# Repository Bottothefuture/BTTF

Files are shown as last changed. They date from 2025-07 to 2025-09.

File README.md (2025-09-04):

Engineering materials
====

This repository contains engineering materials of a self-driven vehicle's model participating in the WRO Future Engineers competition in the season 2022.

# Table of Contents

1. [Repository Contents](#repository-contents)
2. [Project Summary](#project-summary)
3. [Key Features](#key-features)
4. [Hardware Components](#hardware-components)
5. [Mobility System](#mobility-system)
    1. [Steering](#steering)
    2. [Motor Drive](#motor-drive)
    3. [Power System](#power-system)
6. [Detection System](#detection-system)
    1. [Sensors](#sensors)
    2. [Object Detection Pipeline](#object-detection-pipeline)
7. [Software](#software)
8. [Team Members](#team-members)

---

# Repository Contents

* `t-photos` contains 2 photos of the team (an official one and one funny photo with all team members)
* `v-photos` contains 6 photos of the vehicle (from every side, from top and bottom)
* `video` contains the video.md file with the link to a video where driving demonstration exists
* `schemes` contains one or several schematic diagrams in form of JPEG, PNG or PDF of the electromechanical components illustrating all the elements (electronic components and motors) used in the vehicle and how they connect to each other.
* `src` contains code of control software for all components which were programmed to participate in the competition
* `models` is for the files for models used by 3D printers, laser cutting machines and CNC machines to produce the vehicle elements. If there is nothing to add to this location, the directory can be removed.
* `other` is for other files which can be used to understand how to prepare the vehicle for the competition. It may include documentation how to connect to a SBC/SBM and upload files there, datasets, hardware specifications, communication protocols descriptions etc. If there is nothing to add to this location, the directory can be removed.

---

# Project Summary

- This project is a **self driving vehicle** which we have designed for the *WRO Future Engineers 2025 Challenge*
- The aim is for the bot to complete the challenges while scoring full points

## Key Features

- We use an IMU (Intertial Measurment Unit) to calculate how many turns the car has taken and to ensure stabilization
- Front wheels are used for steering and the back wheels are using for powering the car.
- The car has two ultrasonic sensors attached to the front of the car. One faces the right and the other faces forward. These ultrasonic sensors dictate how the car moves and detects obstacles in the car's path
- POWER: 2S LiPo for powering the DC Hobby Gear Motor and ESP32, 2x 3.7 Li-Ion Batterys for powering the servo motors.

---

# Hardware Components

### Components:

- **ESP32 Dev Board** --> Microcontroller which controls the motor and makes decisions based on the values given by the ultrasonic sensors.
- **x2 3.7 Volt Lithium Ion Batterys** --> Power the servo motor for steering.
- **x1 LiPo Battery [11V]** --> Powers the ESP32, L298N Motor Driver and Raspberry Pi
- **RaspberryPi5** --> Analysis of live video feed.
- **RPi Cam** --> For a live video feed and obstacle detection
- **x3 Ultrasonic Sesnors**: Detect obstacles around the vehicle.
- **DC Hobby Gear Motor** --> Powers the rear-wheels so that the car can move forward and backward.
- **Servo Motor** --> Controls the steering of the car and ensures accurate turning.
- **L298N Motor Driver** --> Controls the DC Hobby Gear Motors and ensures they have the adequate power.
- **IMU [BNO055]** --> Calculates the orientation of the vehicles and feeds that information to the ESP to calculate how many turns have been acheived by the vehicle
- **Step-Down Converter** --> Steps down the voltage to 12V
## Mobility System

### Steering
- **Mechanism**: Front wheels turn to steer.
- **Actuator**: A precise servo motor.
- **Implementation**: The servo turns a pivot connected to the wheels, which can still spin freely.
- **Function**: Lets the wheels roll while accurately controlling the direction of the car.

### Motor Drive
- **Primary Motor**: A single DC gear motor.
- **Drive System**: Directly powers the back wheels.
- **Control Method**: Uses PWM to control speed.
- **Performance**: Provides steady power for smooth acceleration.

### Power System
- x2 3.7 Volt Lithium Ion Batteries (These batteries power the servo motor for steering)
- x1 LiPo Battery [11V] --> Powers the ESP32, L298N Motor Driver and RaspberryPi
- Bug [Step Down] Converter --> Reduces the voltage to 12V to ensure safety of the components

## Detection System

### Sensors
- **x3 UltraSonic Sensors**: Detects obstacles around the vehicle. One is facing right and the other is facing foward and the other is facing left.
- **IMU (BNO055)**: Checks the orienation of the vehicle and gives feedback to the car. This allows the car to calculate the number of turns it has taken and allows the vehicle to stop accordingly
- **RPi Cam**: Provides a live video feed to the RaspberryPi which is used to detect obstacles.

### Object Detection Pipeline
- **RPi Cam**: Provides us with real-time footage which is then sent to the Raspberry Pi
- **Raspberry Pi**: The Raspberry Pi recieves the footage sent by the `RPi Cam` and analyzes it detecting obstacles using `OpenCV`. The Raspberry Pi then sends this information to the ESP allowing it to adjust the motors suitably
- **UltraSonic Sensors**: Used for `precise wall-detection` to ensure that out car turns and dodges the walls.

# Software

### Video Feed Analysis:
- For processing our video feed we used `Python's OpenCV`
- We used serial communication to establish a data channel between the RaspberryPi and the ESP32. This allowed them to transfer data efficiently and effectively

### Driving Strategies:
- IMU and accurate calculations to ensure that the bot completes the correct amount of turns before stopping
- `Wall Following` and `Corner Detection` to ensure out car is able to steer clear of the walls and stay on the correct path.
     
## Team Members
 * Samesh Deshmukh - samesh.kostub@gmail.com
 * Rohan Mishra  - rohanmishra.email@gmail.com
 * Aadi Khemka - aadikhemka2020@gmail.com

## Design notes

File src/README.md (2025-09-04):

# WRO Future Engineer's Self Driving Vehicle - Open Round Code:
- This folder contains the reference code for the Open Challenge Round using an ESP32
- This code implements logic like steering, motor control and sensor integration to help this vehicle navigate.

---
# FILE OVERVIEW 📂🗂️
```mermaid
flowchart TD;
   A[src]
   B[**Round 1 Code:**
   OpenRoundChallenge]
   C[**Round 2 Code:**
   ObstacleAvoidingChallenge]
   A --> B
   A --> C
   D[**src**]
   E[**RaspberryPi**]
   C --> D
   C --> E
   F[**raspberrypi**]
   G[**src**]
   B --> F
   B --> G
   H[**switch_control.py**]
   F --> H
   I[**main.cpp**]
   G --> I
   J[**ObstacleDetection.py**]
   E --> J
   K[**main.cpp**]
   D-->K
```
### Round 1: OpenRoundChallenge

|FILE|DETAILS|
|----|---|
|src |The folder containing the code which we upload into the `ESP32`|
|**main.cpp**|The code which is uploaded into the `ESP32` that controls the bot|
|raspberrypi|The folder which is uploaded into the `RaspberryPi`|
|**switch_control.py**|The code which we use for the switch to start the bot|

### Round 2: ObstacleAvoidingChallenge

|FILE|DETAILS|
|----|---|
|src |The folder containing the code which we upload into the `ESP32`|
|**main.cpp**|The code which is uploaded into the `ESP32` that controls the bot|
|RaspberryPi|The folder which is uploaded into the `RaspberryPi`|
|**ObstacleDetection.py**|The code that `detects obstacles` in the car's path and relays that information to the `ESP32`|

---

# HARDWARE USED ⚙️⚙️
- Microcontroller: [ESP-WROOM-32] **ESP32 Dev Board**
- Steering: **Servo Motor**
- IMU (**BNO055**)
- **Raspberry Pi5**
- **RPi Cam** (For Obstacle Detection In The Second Round)
- Sensors: Ultrasonic Sensors [**One facing front and one facing to the right and the other facing to the left**]
- **DC Motor** (Rear Wheel Movement)
- **L298N** Motor Driver
- Battery and Power: (**2x 3.7 Volt Batteries, 1 Li-ion battery**)
---

# HOW TO USE THIS CODE 🧑‍💻🧑‍💻

## Challenge 1: OpenRoundChallenge

### PlatformIO -->
1. Install `PlatformIO` : [**VS Code Extension**]
2. Open the project folder [**OpenRoundChallenge**] in PlatformIO
3. Connect your `ESP32 Board` via USB and in `platformio.ini` confirm your board settings [`board: esp32dev`]
4. **BUILDING & UPLOADING:**
   ```bash
   pio run -- target upload

5. **SETTING UP THE SERIAL MONITOR:**
   ```bash
   pio serial monitor

## Challenge 2: ObstacleAvoidingChallenge

### PlatformIO -->
1. Install `PlatformIO` If You Havent Already : [**VS Code Extension**]
2. Open the project folder [**ObstacleAvoidingChallenge**] in PlatformIO
3. Connect your `ESP32 Board` via USB and in `platformio.ini` confirm your board settings [`board: esp32dev`]
4. **BUILDING & UPLOADING:**
   ```bash
   pio run -- target upload

5. **SETTING UP THE SERIAL MONITOR:**
   ```bash
   pio serial monitor

---

## IMPORTANT INFORMATION 📝📝
--> Tweak angles given in the code to make sure your robot moves straight.
--> You can tweak the values of the if conditions in the turning functions to ensure the vehicles turns accurately
--> Make sure to update the pin numbers in the code to make sure they correspond to the GPIO pins used on the ESP32

---

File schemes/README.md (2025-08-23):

Electromechanical diagrams
====

The schematic diagram is attached below, with all of the electrical connections.

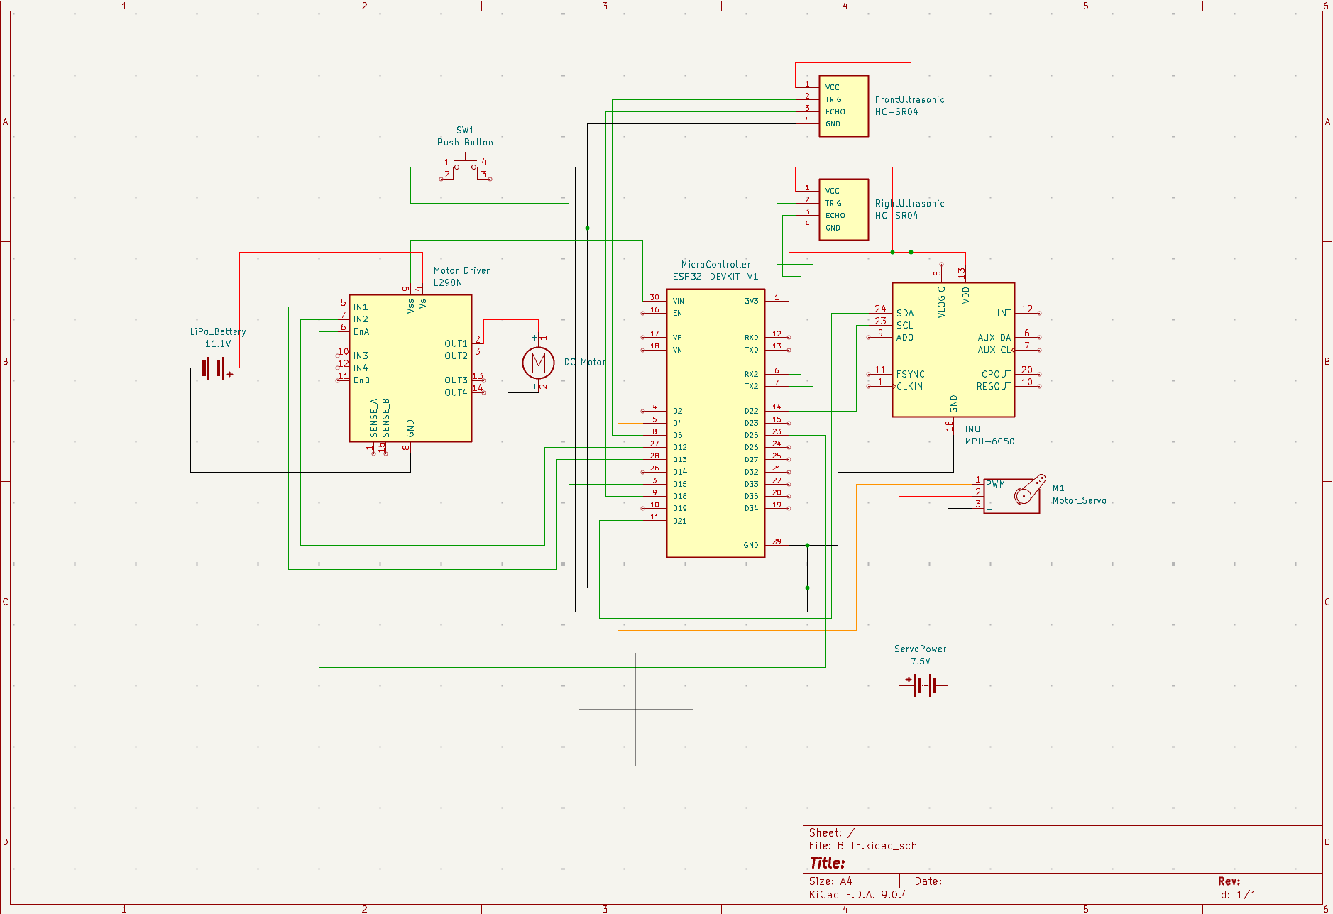
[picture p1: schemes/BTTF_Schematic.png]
Car Schematic


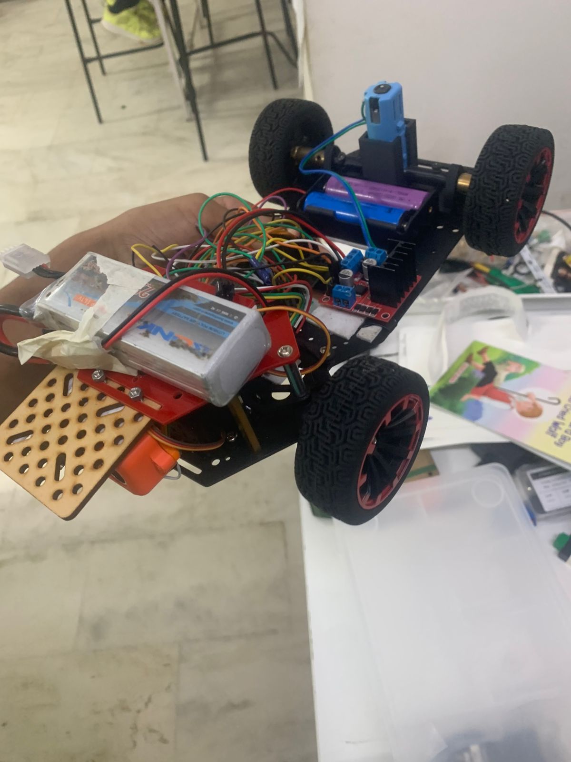
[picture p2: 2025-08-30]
v-photos/SideView.jpeg

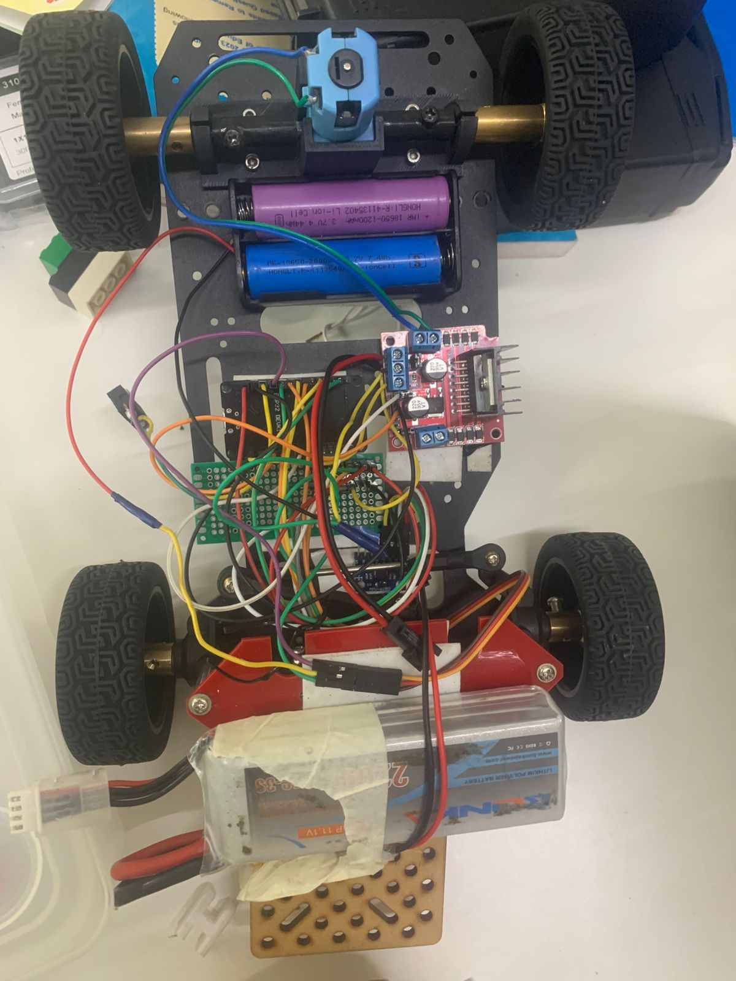
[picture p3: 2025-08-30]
v-photos/TopView.jpeg

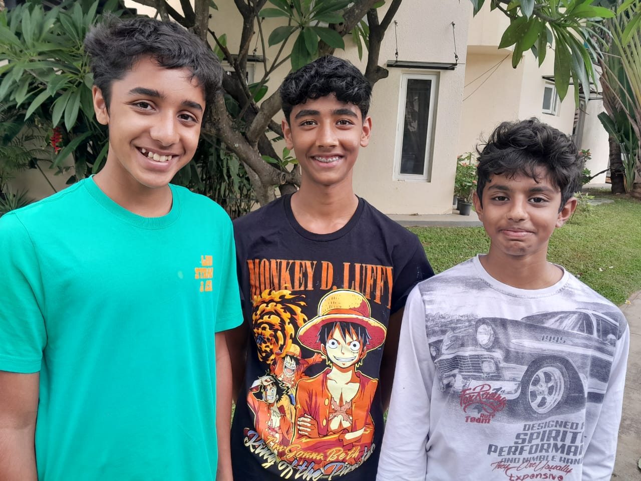
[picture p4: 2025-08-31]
t-photos/BotToTheFuture-Photo.jpeg

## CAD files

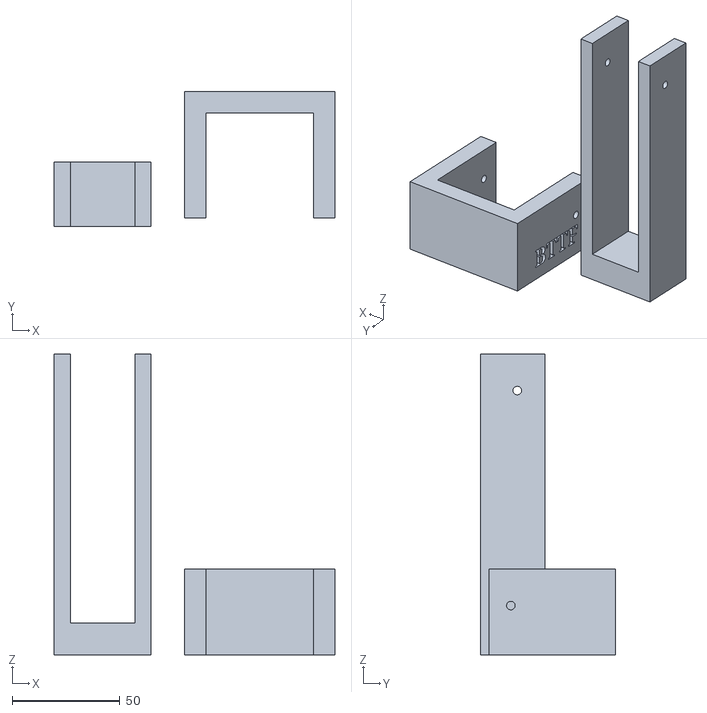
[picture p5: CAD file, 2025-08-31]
models/RPi Cam Mount.stl
130.5 x 63.0 x 140.0

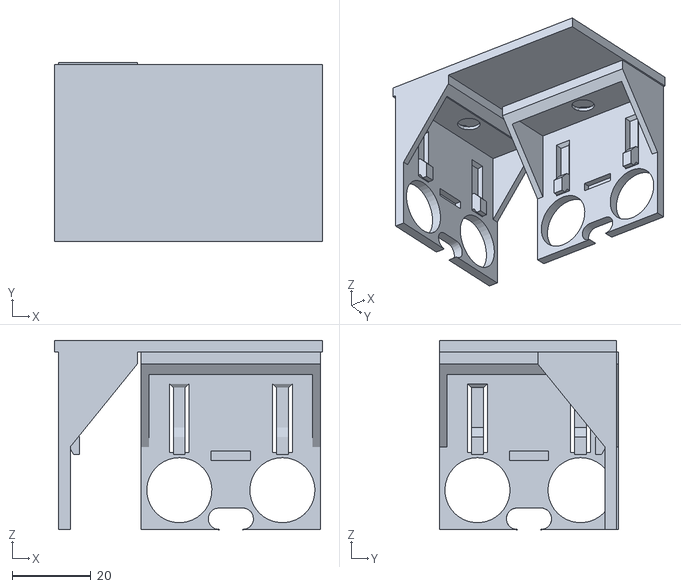
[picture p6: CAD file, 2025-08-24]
models/HC-SR04_Bracket.stl
68.0 x 45.5 x 48.0

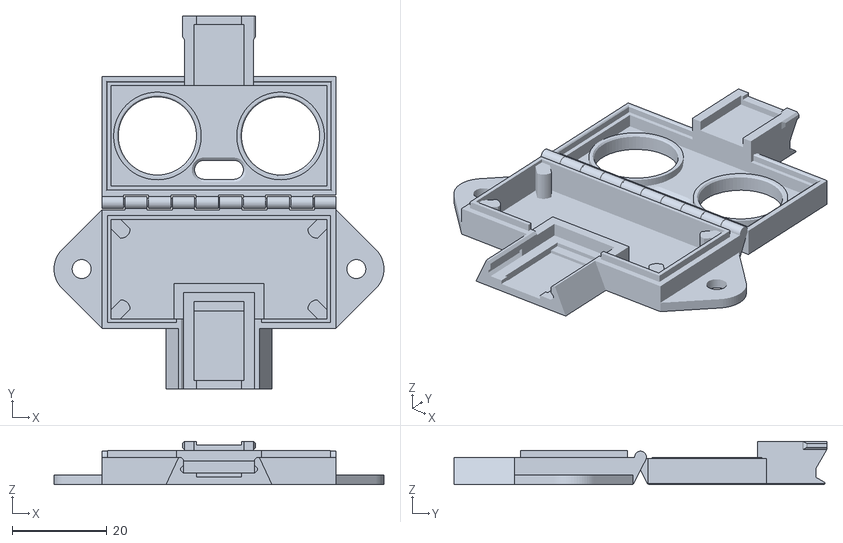
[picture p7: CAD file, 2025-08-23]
models/UltraSonicDistanceCase.stl
69.7 x 78.7 x 9.10

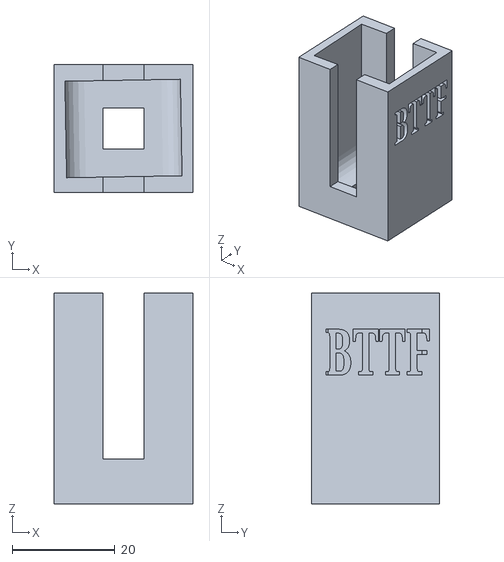
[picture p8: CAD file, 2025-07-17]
models/Motor Scoket Design (3).stl
27.0 x 25.0 x 41.1

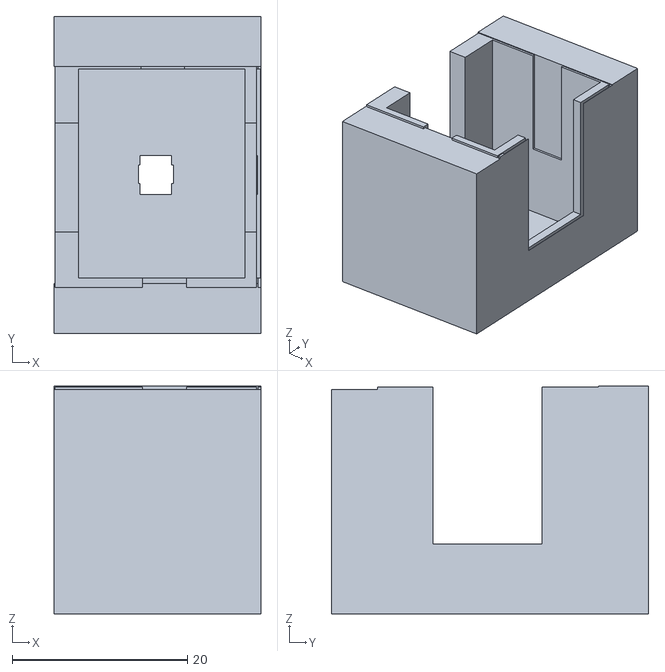
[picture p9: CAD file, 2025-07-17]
models/Motor Scoket Design (1).stl
23.6 x 36.2 x 26.0

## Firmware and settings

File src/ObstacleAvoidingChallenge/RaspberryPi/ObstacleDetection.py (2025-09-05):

# ==============================
# Region-Based Obstacle Navigation for RPi5 + ESP32
# Divides frame into 3 vertical regions for smart turning
# ==============================

import cv2
import numpy as np
from picamera2 import Picamera2
import time
import serial
import RPi.GPIO as GPIO
import board
import busio
import adafruit_bno055
import logging
import os
from datetime import datetime

# ------------------ CONFIG ------------------
SERIAL_PORT = "/dev/ttyUSB0"
BAUD_RATE = 115200
BUTTON_PIN = 17  # physical push button on RPi
LED_PIN = 18  # Status LED

FRAME_W, FRAME_H = 1280, 720

# Frame regions (divide into 3 vertical sections)
LEFT_REGION = (0, FRAME_W // 3)  # 0 to 426
CENTER_REGION = (FRAME_W // 3, 2 * FRAME_W // 3)  # 426 to 853
RIGHT_REGION = (2 * FRAME_W // 3, FRAME_W)  # 853 to 1280

# Servo calibration values (must match ESP32 sketch)
SERVO_LEFT = 20
SERVO_RIGHT = 160
SERVO_STRAIGHT = 90

# Turn intensity configuration based on block size
MIN_TURN = 10  # Minimum turn angle for small/distant blocks
MAX_TURN = 60  # Maximum turn angle for large/close blocks
SIZE_THRESHOLD_SMALL = 1000  # Small block area threshold
SIZE_THRESHOLD_LARGE = 8000  # Large block area threshold

# Speed values
BASE_SPEED = 140
STOP_SPEED = 0

# Color ranges (HSV) - corrected for proper red/green detection
lower_red1 = np.array([171, 57, 84])  # Lower red range
upper_red1 = np.array([184, 255, 255])
lower_red2 = np.array([171, 57, 84])  # Upper red range (wraps around hue)
upper_red2 = np.array([184, 255, 255])

lower_green = np.array([51, 75, 54])  # Green range
upper_green = np.array([85, 255, 255])

# ------------------ LOGGING CONFIG ------------------
# Create logs directory if it doesn't exist
LOGS_DIR = "/home/rpi5wro/wro_fe_project/wro_fe_25/obstacle_round_v2/logs"
os.makedirs(LOGS_DIR, exist_ok=True)

# Generate timestamp for this run
RUN_TIMESTAMP = datetime.now().strftime("%Y%m%d_%H%M%S")
LOG_FILE = os.path.join(LOGS_DIR, f"navigation_log_{RUN_TIMESTAMP}.txt")
VIDEO_FILE = os.path.join(LOGS_DIR, f"navigation_video_{RUN_TIMESTAMP}.avi")

# Setup logging
logging.basicConfig(
    level=logging.INFO,
    format='%(asctime)s - %(levelname)s - %(message)s',
    handlers=[
        logging.FileHandler(LOG_FILE),
        logging.StreamHandler()  # Also print to console
    ]
)
logger = logging.getLogger(__name__)

# Video recording setup
video_writer = None
RECORD_VIDEO = True  # Set to False to disable video recording

# --------------------------------------------

# System setup
GPIO.setmode(GPIO.BCM)
GPIO.setup(BUTTON_PIN, GPIO.IN, pull_up_down=GPIO.PUD_UP)
GPIO.setup(LED_PIN, GPIO.OUT)

# Init Serial to ESP32
ser = serial.Serial(SERIAL_PORT, BAUD_RATE, timeout=0.1)

# Init Camera
picam2 = Picamera2()
config = picam2.create_video_configuration(main={"size": (FRAME_W, FRAME_H), "format": 'RGB888'})

# Init BNO055 IMU
i2c = busio.I2C(board.SCL, board.SDA)
sensor = adafruit_bno055.BNO055_I2C(i2c)

# Global variables
initial_yaw = 0
yaw = 0
front_dist, left_dist, right_dist = 100, 35, 35
last_turn_direction = ""  # Track last turn to help with recovery
recovery_mode = False  # Flag for recovery steering

# Obstacle memory system to handle brief detection losses
last_seen_obstacles = {"red": [], "green": [], "timestamp": 0}
OBSTACLE_MEMORY_TIMEOUT = 1.0  # Remember obstacles for 1 second


# ------------- Helper Functions -------------

def log_navigation_data(steering, state, yaw, front_dist, left_dist, right_dist, red_blocks, green_blocks):
    """Log comprehensive navigation data"""
    timestamp = time.time()

    # Count and summarize blocks
    red_count = len(red_blocks)
    green_count = len(green_blocks)

    red_areas = [w * h for x, y, w, h in red_blocks] if red_blocks else []
    green_areas = [w * h for x, y, w, h in green_blocks] if green_blocks else []

    log_entry = (
        f"T:{timestamp:.3f} | Steering:{steering:.1f} | State:{state} | "
        f"Yaw:{yaw:.1f} | Dist(F:{front_dist},L:{left_dist},R:{right_dist}) | "
        f"RED_blocks:{red_count}{red_areas} | GREEN_blocks:{green_count}{green_areas}"
    )

    logger.info(log_entry)


def led_blink(duration=1.5):
    """Blink status LED"""
    GPIO.output(LED_PIN, GPIO.HIGH)
    time.sleep(duration)
    GPIO.output(LED_PIN, GPIO.LOW)


def calibrate_imu():
    """Calibrate IMU by setting current heading as 0° reference"""
    global initial_yaw
    print("Calibrating IMU...")
    time.sleep(1)  # Let IMU settle
    raw_yaw = sensor.euler[0]
    if raw_yaw is not None:
        initial_yaw = raw_yaw
        print(f"IMU calibrated. Initial heading: {initial_yaw:.1f}° set as 0° reference")
    else:
        print("Warning: Could not read IMU for calibration")
        initial_yaw = 0


def read_yaw():
    """Read relative yaw from BNO055"""
    global initial_yaw
    raw_yaw = sensor.euler[0]
    if raw_yaw is not None:
        relative_yaw = raw_yaw - initial_yaw
        # Normalize to [-180, 180]
        if relative_yaw > 180:
            relative_yaw -= 360
        elif relative_yaw < -180:
            relative_yaw += 360
        return relative_yaw
    return 0.0


def read_from_esp32():
    """Read ultrasonic distances from ESP32"""
    global front_dist, left_dist, right_dist
    ser.write(b"GET\n")
    try:
        line = ser.readline().decode().strip()
        if line.startswith("DIST"):
            _, f, l, r = line.split(",")
            front_dist = int(float(f))
            left_dist = int(float(l))
            right_dist = int(float(r))
    except:
        pass


def send_to_esp32(speed, steering):
    """Send motor speed + steering angle to ESP32"""
    command = f"{int(speed)},{int(steering)}\n"
    ser.write(command.encode())


def update_obstacle_memory(red_blocks, green_blocks):
    """Update obstacle memory and return enhanced block lists"""
    global last_seen_obstacles

    current_time = time.time()

    # Update memory with current detections
    if red_blocks or green_blocks:
        last_seen_obstacles["red"] = red_blocks
        last_seen_obstacles["green"] = green_blocks
        last_seen_obstacles["timestamp"] = current_time
        logger.debug(f"Obstacle memory updated: {len(red_blocks)} red, {len(green_blocks)} green")
    else:
        # Check if we should use remembered obstacles
        time_since_last_detection = current_time - last_seen_obstacles["timestamp"]
        if time_since_last_detection < OBSTACLE_MEMORY_TIMEOUT:
            # Use remembered obstacles if recent enough
            red_blocks = last_seen_obstacles["red"]
            green_blocks = last_seen_obstacles["green"]
            logger.debug(
                f"Using remembered obstacles: {len(red_blocks)} red, {len(green_blocks)} green (age: {time_since_last_detection:.2f}s)")
        else:
            # Clear old memory
            last_seen_obstacles = {"red": [], "green": [], "timestamp": 0}

    return red_blocks, green_blocks


def detect_obstacles(frame):
    """Detect red and green obstacles and return their positions"""
    hsv = cv2.cvtColor(frame, cv2.COLOR_BGR2HSV)

    # Create masks for red and green
    mask_red = cv2.inRange(hsv, lower_red1, upper_red1) | cv2.inRange(hsv, lower_red2, upper_red2)
    mask_green = cv2.inRange(hsv, lower_green, upper_green)

    # Find contours
    red_contours, _ = cv2.findContours(mask_red, cv2.RETR_EXTERNAL, cv2.CHAIN_APPROX_SIMPLE)
    green_contours, _ = cv2.findContours(mask_green, cv2.RETR_EXTERNAL, cv2.CHAIN_APPROX_SIMPLE)

    red_blocks = []
    green_blocks = []
    min_area = 500  # Reduced minimum area for better detection of distant blocks

    # Process red contours
    for contour in red_contours:
        area = cv2.contourArea(contour)
        if area > min_area:
            x, y, w, h = cv2.boundingRect(contour)
            if h > 15 and w > 15:  # More permissive size requirements
                red_blocks.append((x, y, w, h))
                logger.debug(f"RED block detected: x={x}, y={y}, w={w}, h={h}, area={area}")

    # Process green contours
    for contour in green_contours:
        area = cv2.contourArea(contour)
        if area > min_area:
            x, y, w, h = cv2.boundingRect(contour)
            if h > 15 and w > 15:  # More permissive size requirements
                green_blocks.append((x, y, w, h))
                logger.debug(f"GREEN block detected: x={x}, y={y}, w={w}, h={h}, area={area}")

    # Log detection summary
    if red_blocks or green_blocks:
        logger.debug(f"Detection summary: {len(red_blocks)} red blocks, {len(green_blocks)} green blocks")

    return red_blocks, green_blocks


def get_region(x):
    """Determine which region the x-coordinate falls into"""
    if LEFT_REGION[0] <= x < LEFT_REGION[1]:
        return "LEFT"
    elif CENTER_REGION[0] <= x < CENTER_REGION[1]:
        return "CENTER"
    elif RIGHT_REGION[0] <= x < RIGHT_REGION[1]:
        return "RIGHT"
    return "UNKNOWN"


def calculate_turn_intensity(block_area):
    """Calculate turn intensity based on block size (area)"""
    # Larger blocks = closer = need sharper turns
    # Smaller blocks = farther = need gentler turns

    if block_area <= SIZE_THRESHOLD_SMALL:
        # Small block (far away) - gentle turn
        intensity = MIN_TURN
        size_category = "SMALL"
    elif block_area >= SIZE_THRESHOLD_LARGE:
        # Large block (close) - sharp turn
        intensity = MAX_TURN
        size_category = "LARGE"
    else:
        # Medium block - interpolate between min and max
        ratio = (block_area - SIZE_THRESHOLD_SMALL) / (SIZE_THRESHOLD_LARGE - SIZE_THRESHOLD_SMALL)
        intensity = MIN_TURN + (MAX_TURN - MIN_TURN) * ratio
        size_category = "MEDIUM"

    print(f"Block area: {block_area} -> {size_category} -> Turn intensity: {intensity:.1f}°")
    logger.debug(f"Turn calculation: area={block_area} -> {size_category} -> intensity={intensity:.1f}°")
    return intensity, size_category


def calculate_steering(blocks, color="none"):
    """Calculate steering based on block positions, size, and WRO rules"""

    steering_adjustment = 0
    turn_type = ""

    if not blocks:
        if front_dist < 55 and left_dist < 90 < right_dist:
            steering_adjustment = SERVO_RIGHT - SERVO_STRAIGHT
            turn_type = f"TURN_RIGHT"
        elif front_dist < 55 and left_dist > 90 > right_dist:
            steering_adjustment = SERVO_LEFT - SERVO_STRAIGHT
            turn_type = f"TURN_LEFT"
        return steering_adjustment, turn_type

    # Find the largest (closest) block
    largest_block = max(blocks, key=lambda b: b[2] * b[3])  # w * h
    x, y, w, h = largest_block
    block_center_x = x + w // 2
    block_area = w * h
    region = get_region(block_center_x)

    # Calculate turn intensity based on block size
    base_intensity, size_category = calculate_turn_intensity(block_area)


    if color == "GREEN":
        # GREEN blocks: Must turn LEFT around them
        if region == "LEFT":
            # Green block on left - LEFT turn (good position)
            steering_adjustment = -base_intensity
            turn_type = f"{size_category}_LEFT"
        elif region == "CENTER":
            # Green block in center - MEDIUM LEFT turn (increase intensity slightly)
            steering_adjustment = -(base_intensity * 1.2)  # 20% more aggressive
            turn_type = f"{size_category}_CENTER_LEFT"
        elif region == "RIGHT":
            # Green block on right - GENTLE LEFT turn (need to get to left side)
            steering_adjustment = -(base_intensity * 0.8)  # 20% less aggressive
            turn_type = f"{size_category}_SLIGHT_LEFT"

    elif color == "RED":
        # RED blocks: Must turn RIGHT around them
        if region == "LEFT":
            # Red block on left - GENTLE RIGHT turn (need to get to right side)
            steering_adjustment = base_intensity * 0.8  # 20% less aggressive
            turn_type = f"{size_category}_SLIGHT_RIGHT"
        elif region == "CENTER":
            # Red block in center - MEDIUM RIGHT turn (increase intensity slightly)
            steering_adjustment = base_intensity * 1.2  # 20% more aggressive
            turn_type = f"{size_category}_CENTER_RIGHT"
        elif region == "RIGHT":
            # Red block on right - RIGHT turn (good position)
            steering_adjustment = base_intensity
            turn_type = f"{size_category}_RIGHT"

    elif color == "none":
        if front_dist < 55 and left_dist < 90 < right_dist:
            steering_adjustment = SERVO_RIGHT
            turn_type = f"TURN_RIGHT"
        elif front_dist < 55 and left_dist > 90 > right_dist:
            steering_adjustment = SERVO_LEFT
            turn_type = f"TURN_LEFT"



    # Ensure steering adjustment doesn't exceed limits
    max_adjustment = 55  # Maximum steering adjustment
    steering_adjustment = max(-max_adjustment, min(max_adjustment, steering_adjustment))

    print(f"{color} block in {region} region at ({block_center_x}, {y}) -> {turn_type} (area={block_area})")
    logger.debug(
        f"Steering calculation: {color} block in {region} at ({block_center_x},{y}) -> {turn_type} | area={block_area} | adjustment={steering_adjustment:.1f}")
    return steering_adjustment, turn_type


def decide_steering():
    """Main decision logic for steering"""
    global yaw, last_turn_direction, recovery_mode

    # Read current yaw
    yaw = read_yaw()

    # Get obstacle detections
    frame = picam2.capture_array()
    red_blocks, green_blocks = detect_obstacles(frame)

    # Update obstacle memory and get enhanced detection
    red_blocks, green_blocks = update_obstacle_memory(red_blocks, green_blocks)

    steering = SERVO_STRAIGHT
    state = "STRAIGHT"

    # Priority: Handle obstacles based on proximity (size), not color preference
    closest_block = None
    closest_color = None
    closest_area = 0

    # Log all detected blocks for debugging
    if red_blocks or green_blocks:
        all_red_areas = [w * h for x, y, w, h in red_blocks]
        all_green_areas = [w * h for x, y, w, h in green_blocks]
        logger.debug(
            f"All detections: RED blocks={len(red_blocks)}{all_red_areas}, GREEN blocks={len(green_blocks)}{all_green_areas}")

    # Find the closest block among all detected blocks
    if red_blocks:
        largest_red = max(red_blocks, key=lambda b: b[2] * b[3])
        red_area = largest_red[2] * largest_red[3]
        if red_area > closest_area:
            closest_block = largest_red
            closest_color = "RED"
            closest_area = red_area
            logger.debug(f"Largest RED block: area={red_area}")

    if green_blocks:
        largest_green = max(green_blocks, key=lambda b: b[2] * b[3])
        green_area = largest_green[2] * largest_green[3]
        if green_area > closest_area:
            closest_block = largest_green
            closest_color = "GREEN"
            closest_area = green_area
            logger.debug(f"Largest GREEN block: area={green_area}")
        elif green_blocks:  # Log even if not closest
            logger.debug(f"GREEN block present but smaller: area={green_area} vs RED area={closest_area}")

    closest_blocks = [closest_block]
    adjustment, turn_type = calculate_steering(closest_blocks, closest_color)
    steering = SERVO_STRAIGHT + adjustment
    state = f"{closest_color}_{turn_type}"

    if turn_type.startswith("TURN"):
        steering = min(max(SERVO_LEFT, steering), SERVO_RIGHT)

        # Log comprehensive navigation data
        log_navigation_data(steering, state, yaw, front_dist, left_dist, right_dist, red_blocks, green_blocks)

        # Draw debug visualization
        frame_debug = draw_debug(frame, red_blocks, green_blocks, steering, state)
        cv2.imshow("Region-Based Navigation", frame_debug)

        return steering, state

    # Handle the closest (most urgent) obstacle
    if closest_block is not None:
        # Create a list with just the closest block for calculate_steering

        if closest_color == "GREEN":
            last_turn_direction = "LEFT"
        else:  # RED
            last_turn_direction = "RIGHT"

        recovery_mode = False  # Reset recovery when actively avoiding

        logger.info(f"PRIORITY: {closest_color} block (area={closest_area}) is closest - handling first")
        print(f"PRIORITY: {closest_color} block (area={closest_area}) is closest - handling first")

    else:

        # No obstacles detected - apply recovery logic
        logger.debug(f"No obstacles detected - red_blocks={len(red_blocks)}, green_blocks={len(green_blocks)}")

        recovery_steering = 0

        # If we just finished avoiding an obstacle, apply counter-steering
        if abs(yaw) > 5:  # Robot is not straight
            if last_turn_direction == "RIGHT" and yaw > 5:
                # After right turn, robot is angled right - steer LEFT to center
                recovery_steering = -15  # Counter-steer left
                state = "RECOVERY_LEFT_AFTER_RIGHT"
                recovery_mode = True

            elif last_turn_direction == "LEFT" and yaw < -0:
                # After left turn, robot is angled left - steer RIGHT to center
                recovery_steering = 15  # Counter-steer right
                state = "RECOVERY_RIGHT_AFTER_LEFT"
                recovery_mode = True

        # Apply yaw correction to get back to 0°
        error = 0 - yaw  # Target is 0° (straight from start)
        yaw_correction = error * 0.8  # Stronger correction for faster recovery

        # Combine recovery steering with yaw correction
        total_correction = recovery_steering + yaw_correction
        steering = SERVO_STRAIGHT + total_correction

        if not recovery_mode:
            state = "STRAIGHT_YAW_CORRECTION"

        print(
            f"No obstacles - Yaw: {yaw:.1f}°, Recovery: {recovery_steering}, YawCorr: {yaw_correction:.1f}, Total: {total_correction:.1f}")
        logger.debug(
            f"Recovery mode: yaw={yaw:.1f}°, recovery_steering={recovery_steering}, yaw_correction={yaw_correction:.1f}, total={total_correction:.1f}")

        # Clear last turn direction if we're back to straight
        if abs(yaw) < 3:
            last_turn_direction = ""
            recovery_mode = False

    # Limit steering to valid range
    steering = min(max(SERVO_LEFT, steering), SERVO_RIGHT)

    # Log comprehensive navigation data
    log_navigation_data(steering, state, yaw, front_dist, left_dist, right_dist, red_blocks, green_blocks)

    # Draw debug visualization
    frame_debug = draw_debug(frame, red_blocks, green_blocks, steering, state)
    cv2.imshow("Region-Based Navigation", frame_debug)

    return steering, state


def draw_debug(frame, red_blocks, green_blocks, steering, state):
    """Draw debug visualization with regions and obstacles"""
    debug_frame = frame.copy()

    # Draw region dividers
    cv2.line(debug_frame, (FRAME_W // 3, 0), (FRAME_W // 3, FRAME_H), (255, 255, 255), 2)
    cv2.line(debug_frame, (2 * FRAME_W // 3, 0), (2 * FRAME_W // 3, FRAME_H), (255, 255, 255), 2)

    # Label regions
    cv2.putText(debug_frame, "LEFT", (50, 50), cv2.FONT_HERSHEY_SIMPLEX, 1, (255, 255, 255), 2)
    cv2.putText(debug_frame, "CENTER", (FRAME_W // 2 - 50, 50), cv2.FONT_HERSHEY_SIMPLEX, 1, (255, 255, 255), 2)
    cv2.putText(debug_frame, "RIGHT", (FRAME_W - 150, 50), cv2.FONT_HERSHEY_SIMPLEX, 1, (255, 255, 255), 2)

    # Draw red blocks
    for x, y, w, h in red_blocks:
        cv2.rectangle(debug_frame, (x, y), (x + w, y + h), (0, 0, 255), 3)
        center_x = x + w // 2
        area = w * h
        region = get_region(center_x)
        cv2.putText(debug_frame, f"RED-{region}", (x, y - 30), cv2.FONT_HERSHEY_SIMPLEX, 0.6, (0, 0, 255), 2)
        cv2.putText(debug_frame, f"Area: {area}", (x, y - 10), cv2.FONT_HERSHEY_SIMPLEX, 0.5, (0, 0, 255), 2)

    # Draw green blocks
    for x, y, w, h in green_blocks:
        cv2.rectangle(debug_frame, (x, y), (x + w, y + h), (0, 255, 0), 3)
        center_x = x + w // 2
        area = w * h
        region = get_region(center_x)
        cv2.putText(debug_frame, f"GREEN-{region}", (x, y - 30), cv2.FONT_HERSHEY_SIMPLEX, 0.6, (0, 255, 0), 2)
        cv2.putText(debug_frame, f"Area: {area}", (x, y - 10), cv2.FONT_HERSHEY_SIMPLEX, 0.5, (0, 255, 0), 2)
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

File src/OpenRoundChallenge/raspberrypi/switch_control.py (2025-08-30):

import RPi.GPIO as GPIO
import serial
import time


GPIO.setmode(GPIO.BCM)

button_pin = 23
button = False

GPIO.setup(button_pin, GPIO.IN, pull_up_down=GPIO.PUD_UP)

ser = serial.Serial('/dev/ttyUSB0', 9600, timeout=1)
ser.write(b"test\n")
print(ser.readline())

while True:
    button_state = GPIO.input(button_pin)

    if button_state == GPIO.LOW:  # If using PUD_UP, button pressed means LOW
        print("Button Pressed!")
        time.sleep(0.2)  # Debounce delay
        button = True
        ser.write(b"START\n")
        break

    time.sleep(0.1)  # Small delay to prevent busy-waiting

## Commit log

2025-08-23 Rename Glorious Blad.stl to UltraSonicDistanceCase.stl
    [UltraSonicDistanceCase.stl]
2025-08-23 Rename Incredible Hango-Elzing.stl to Parts_Car.stl
    [Incredible Hango-Elzing.stl, Parts_Car.stl]
2025-08-24 Rename Epic Uusam-Hillar.stl to HC-SR04_Bracket.stl
    [HC-SR04_Bracket.stl]
2025-08-31 Rename Fantabulous Waasa.stl to RPi Cam Mount.stl
    [RPi Cam Mount.stl]
